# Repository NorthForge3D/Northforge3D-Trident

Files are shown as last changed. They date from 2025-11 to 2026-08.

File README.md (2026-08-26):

Project Currently on Hold (Aug 25, 2026). To come back better - with something completely different. Github update soon, all new. Youtube videos to come. New site coming online. We haven't abandoned it, we're just going to do it better!

<p align="center">
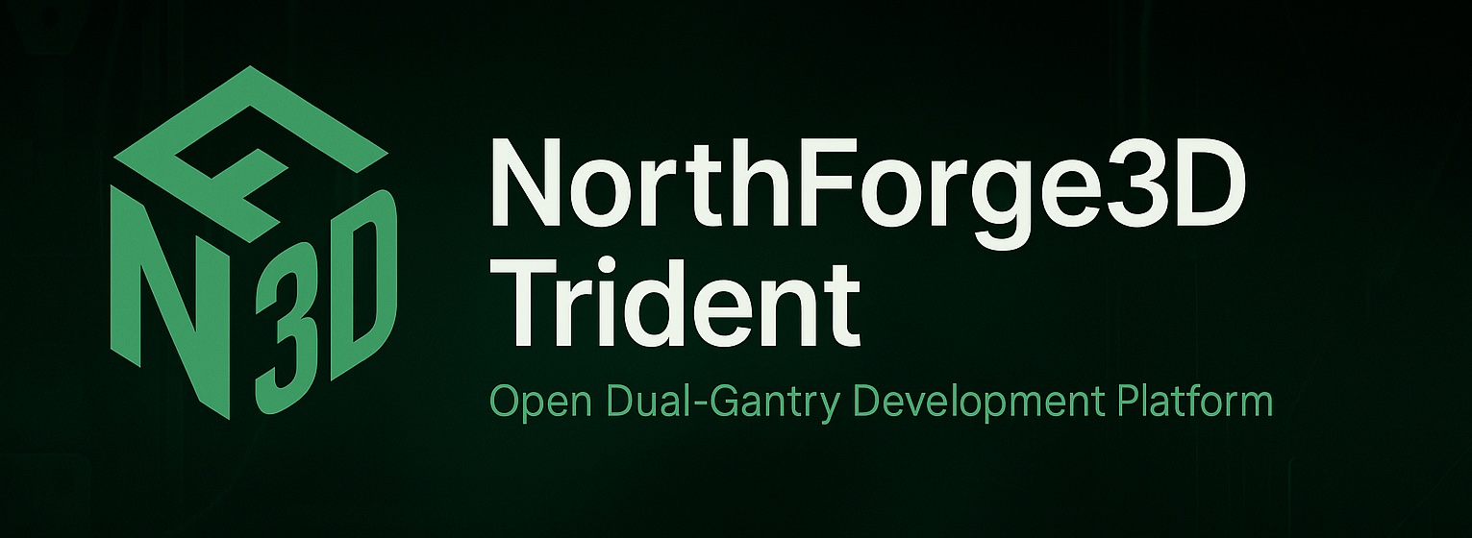
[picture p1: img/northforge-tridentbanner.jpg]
NorthForge3D Trident Banner
  
</p>

# NorthForge3D Trident – Open Development Platform for the Deuce  
### A dual-gantry proof-of-concept for the upcoming **NorthForge3D Deuce** – a next-generation, high-precision IDEX 3D printer.

---

## ⚠️ Experimental Project — Do Not Build Yet

This repository is under **active development** and contains **early, unstable, and rapidly changing work**.

The NorthForge3D Trident is our **motion lab**: a Trident-footprint, dual-gantry platform we’re using to prove out the mechanics, motion control, and behavior that will define the Deuce.

It is **not**:

- A finished printer  
- A drop-in Voron derivative  
- A recommended build at this stage  

- It will be a modded Voron Trident, with dual gantry printing.
- A really cool build if you want to watch and build one yourself
  
If you’d like to follow the progress—and get updates as this build and eventually our printer the Deuce evolve—you can start here:

👉 **Follow the Trident Build and the Deuce as They Evolve**  
https://northforge3d.com/forge-with-us/

👉 **Main Site**  
https://northforge3d.com

A full video series will be published once the Modded Trident design stabilizes.

---

## 🔥 What This Project Is

This repository documents the **engineering, testing, and evolution** of the NorthForge3D **Trident-based dual-gantry test platform**.

Think of it as our:

- Dual-gantry motion testbed  
- Toolhead choreography sandbox  
- Collision-avoidance and synchronization playground  
- Early electronics and layout experiment  
- Mechanical R&D platform for the Deuce

Everything here is **iterating frequently**. Expect redesigns, experiments, and the occasional controlled chaos.

---

## 🎯 Goals of the Proof-of-Concept Printer

### 1. Validate Dual-Gantry Motion

We need a reliable platform to test:

- Independent toolheads  
- Parallel / mirror / duplication print modes  
- Coordinated multi-tool workflows  
- High-speed motion with tight synchronization  
- Collision detection / avoidance strategies  

### 2. Redesign Major Subsystems

While this machine starts from a Trident footprint, it will diverge significantly:

- Fully redesigned **bottom section**  
  - No Voron skirt  
  - **Inverted electronics** visible inside the chamber  
  - Clean, service-friendly layout
- Raspberry Pi on a custom plate with **side-facing ports**  
- Redesigned **dual (eventual quad) gantry**  
- Lightweight toolheads  
- Filament cutter v2  
- New cable routing approaches  
- Modified or fully custom gantry components  
- Custom motors, pulley arrangements, and belt routing as needed  

### 3. Prototype a Production-Forward Layout

This proof-of-concept exists to test:

- Thermal behavior inside the frame  
- Cable access and serviceability  
- Component placement and reach  
- Mechanical accessibility and maintenance paths  
- The aesthetic and functional “feel” of a future NorthForge3D printer  

All of that informs the production-grade **Deuce**.

---

## 🧱 Hardware Decisions (So Far)

Current planned / in-use hardware includes:

- **0.9° NEMA 17 motors** – ~0.54 Nm, 42×48 mm  
- **0.9° pancake steppers** for toolheads  
- **T8×2 (single-start) lead screws** for ultra-fine Z resolution  
- **Klipper-based electronics**  
- Raspberry Pi with external-facing I/O  
- Additional hardware will be added as testing continues

Hardware choices may change as we prove things out.

---

## 📌 Status: Early Development

This repository is currently being **cleaned**, **reorganized**, and aligned to the new design direction.

In the near term:

- Remaining Voron-specific stl's will be removed - we'll re-export them with mods when we are done.  
- Bottom section redesign mod 
- Early dual-gantry motion tests will be shared  
- CAD development will continue in Fusion 360  
- Development logs will grow as milestones are reached, as we work  

Expect the design and structure here to change often as the NF3D Modded Trident comes together.

---

## 📅 Development Logs

We’re documenting progress in plain language as the project evolves. Logs will capture:

- CAD progress  
- Mechanical R&D  
- Firmware experiments  
- Toolhead ideas and tests  
- Renders / photos as the machine takes shape  
- Iterative design changes  
- Lessons learned and upcoming plans  

Long term, these logs will pair with a video series and deeper written documentation.

---

## 🧪 This Is Not the Deuce

The final **NorthForge3D Deuce** will be:

- Larger and fully enclosed  
- Built on a larger extrusion frame  
- Outfitted with production-grade electronics  
- Running refined dual-gantry mechanisms  
- Built with collision-resistant logic and robust safety considerations  
- Equipped with custom motors, pulleys, and motion components  
- Designed with full internal lighting and service access paths  

The Trident mod exists to **perfect the motion, firmware, and mechanical fundamentals** before we commit them to the Deuce. 

We've decided to use this printer to show you - how to build a printer that will outdo any printer you can buy off the shelf. You build it, you understand it, you can break it and fix it... it's what we do and you should to. 

A printer you build is your own. A Voron you build is better, faster, and more precise than your Bambu, any day of the week (sorry Bambu fan boys/girls)

---

## 🔗 Follow the Project

👉 **Website**  
https://northforge3d.com

👉 **Subscribe for Development Updates**  
https://northforge3d.com/forge-with-us/

👉 **Deuce Engineering Blog**  
https://northforge3d.com/forge-updates/deuce-updates/

👉 **Facebook** (short updates & announcements)  
https://www.facebook.com/NorthForge3D/

👉 **YouTube** (full build series coming)  
https://www.youtube.com/@northforge3d

👉 **Instagram** (visual progress, behind the scenes)  
https://www.instagram.com/northforge3d/

---

## 📜 License

This project is currently released under the **GNU GPLv3** license.

As the proof-of-concept solidifies, we will clearly identify:

- Which components originate from Voron Trident  
- Which mods are original NorthForge3D designs  

The license will remain **GPLv3**.

---

## 🤝 Contributions

This is an active engineering development project.  
Contributions and discussion are welcome — just be aware that:

- The design moves quickly  
- Files may be reorganized  
- Some ideas will be replaced as better solutions emerge  

If you’d like to collaborate, please open an **issue** or a **pull request**.

---

### 📘 Additional Project Files

👉 **[CHANGELOG.md](./CHANGELOG.md)** — Full development history  
👉 **[DESIGN-NOTES.md](./DESIGN-NOTES.md)** — Thoughts / Decisions / The Why

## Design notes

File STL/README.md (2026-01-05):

# STL Files — NF3D Trident

This directory contains STL files for the **NF3D Trident** build.

All STL files housed here have been **validated through real-world use** and have been printed and confirmed on an operating printer. These files may be downloaded, printed, and used to build your own NF3D Trident.

Most STL files in this directory **diverge from the stock Voron Trident design**. They are **not interchangeable** with standard Voron Trident parts unless explicitly stated. Substituting these parts into a stock Trident build, or vice versa, may result in fitment or functional issues.

Only tested, confirmed parts are included here. Experimental or in-progress designs are intentionally excluded.

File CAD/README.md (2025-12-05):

# NorthForge3D – CAD Directory

This directory contains all CAD work related to the NorthForge3D Trident-based
proof-of-concept printer. The goal of this phase is to validate key design 
modifications in CAD before physical construction begins.

The work here includes:
- A redesigned electronics bay
- Structural frame stiffeners
- Updated panel system
- Modified gantry and motion components
- A complete reassembled model for fitment and validation

The CAD in this directory represents the *working* design files.  
Reference files for the original Trident configuration are included for comparison.

For more information about the NorthForge3D project and the vision behind our printers,
visit **https://northforge3d.com**

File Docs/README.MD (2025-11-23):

# Documentation — NorthForge3D Trident

This directory contains documentation, notes, images, and design references for the Trident dual-gantry proof-of-concept.

---

### Expected Contents

- Mechanical notes  
- Motion-system diagrams  
- Testing procedures  
- Renders and photos  
- Early development reports  
- Future Deuce reference material  

More documentation will be added as development progresses.

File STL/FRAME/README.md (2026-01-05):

# Frame — NF3D Trident

The parts in this directory are **optional frame stiffeners** designed specifically for the **first dual-gantry NF3D Trident**.

These parts are included for two reasons:

1. **Frame Stiffening**  
   When installed, these parts increase overall frame rigidity.  
   Use of these parts requires **additional M5 fasteners and T-nuts** beyond the standard Trident bill of materials.

2. **Frame Squaring Aid (Use With Caution)**  
   If printed on a **well-tuned printer** and **confirmed to be exactly square using a machinist square**, these parts can assist in building and squaring the entire frame during assembly.

   ⚠️ **Warning:**  
   If printer accuracy and part squareness are **not verified with a machinist square**, these parts may **lock errors into the frame** rather than correct them. In this case, they can work *against* you instead of helping.

These parts diverge from the stock Voron Trident design and are intended for use only with the NF3D Trident geometry and documentation.

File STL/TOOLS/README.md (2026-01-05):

# Tools — NF3D Trident

This directory contains **tools and jigs** used to build the **NF3D Trident**.

Files in this directory are **not printer parts**. They are intended to assist with fabrication, alignment, and modification tasks during the build process (e.g. drilling jigs, alignment guides, and setup tools).

Some tools in this directory may be **generally useful** for other builds or projects. Others are **specific to the NF3D Trident** and are designed to be used in conjunction with this printer’s geometry and documentation.

All tools housed here have been **used and validated** during the NF3D Trident build process. Improper use may result in permanent damage to parts or materials—review the associated documentation before use.

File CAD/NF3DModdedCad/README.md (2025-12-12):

# NF3D Mods to Trident Cad

This directory contains the complete reassembled CAD model of the 
NorthForge3D Trident proof-of-concept printer.

This assembly links together:
- Frame subsystem
- Electronics bay
- Panels
- Gantry and motion system

Purpose:
- Validate clearances
- Confirm alignment between subsystems
- Check interference and fitment
- Visualize the printer as a whole prior to prototype construction

This assembly is the single source of truth for reviewing the current state 
of the printer design.

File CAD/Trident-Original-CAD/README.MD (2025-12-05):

## Trident Original CAD – Reference Only

This directory contains the pristine, unmodified CAD files of the original 
Voron Trident design.

These files are used strictly for:
- Measurement reference
- Comparison against NorthForge3D modifications
- Alignment checks
- Ensuring compatibility during early development phases

Do not modify these files.  
They serve as the fixed reference baseline for the entire project.

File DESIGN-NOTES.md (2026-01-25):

# DESIGN NOTES

Design Notes exist to capture **why** decisions were made, not just **what** was done.

While `CHANGELOG.md` records concrete actions and visible progress, this file documents the reasoning, tradeoffs, constraints, and forward-looking thoughts that led to those actions. Together, they form a linked record:

- **CHANGELOG.md** → what was built, changed, or tested  
- **DESIGN-NOTES.md** → why those choices were made, and what alternatives were considered

Entries here may include incomplete ideas, exploratory thinking, or decisions that evolve over time. That is intentional. This file is a living design journal meant to provide context for future work, explain past decisions to collaborators or builders, and make the project’s direction understandable long after individual commits are forgotten.

## 2025-01-24 — Dual Gantry Trident: v1 Build Volume Decision (Reduced X)

For the first dual-gantry Trident build, I am intentionally **accepting a reduced X build volume** rather than modifying the bed position, frame depth, or gantry geometry.

With two toolheads sharing the X axis, a stock-geometry Trident naturally loses usable X travel equivalent to roughly one toolhead width. In this configuration, the expected expectation for v1 is approximately:

- **~230 mm X**
- **~300 mm Y**
- **~200 mm Z**

This is a deliberate choice.

While there are multiple ways to recover X travel (moving the bed rearward, redesigning bed mounts, extending the frame depth, longer rails, or re-centering gantries), each introduces additional variables that complicate early tuning and validation.

For the v1 dual-gantry platform, the priority is:

- Validate dual-gantry mechanics and synchronization
- Tune motion, resonance, and input shaping without custom geometry side effects
- Observe real-world behavior of two moving toolheads under load
- Identify print artifacts with confidence they are *motion-system related*, not geometry-induced
- Establish a known-good baseline before expanding the envelope

Introducing custom bed mounts or frame extensions at this stage risks creating failure modes that are difficult to isolate (e.g. tall-print artifacts, thermal relaxation, shifted center of mass, or stiffness asymmetries).

A slightly reduced build volume is an acceptable trade-off in exchange for:
- cleaner diagnostics
- faster iteration
- higher confidence in conclusions drawn from test prints

Once the dual-gantry system is mechanically and dynamically validated, a future revision can safely reclaim X travel through controlled, well-understood changes (longer rails, adjusted frame depth, or revised bed mounting).

This decision is intentional and scoped to **v1 validation**, not a permanent limitation.

## 2025-01-21 — Skirt Design Thoughts, Bed Mount Design

- Designing skirt pieces
  - Bottom Lexan electronics panel will need to bolt to the skirts and corner blocks
  - Corner blocks and skirts will include an inset to allow a flat bottom surface
  - Interface will include designed components that bolt into the skirts and corner blocks to retain the electronics panel

- Voron skirts are very open
  - For the inverted electronics bay, temperature control is required
  - Electronics bay is sealed from the chamber via the removable clear access panel
  - Control board can measure its own temperature; no separate thermistor required
  - Fans will control airflow
  - Skirt pieces will be mostly closed to allow software-based temperature control of the electronics bay

- Bed mount redesign
  - Bed needs to move rearward by approximately 40 mm
  - First revision must prioritize maximum stiffness
  - PAHT-CF will be used for initial bed mounts
    - Printable — confirmed
    - Shrinkage and annealing behavior must be characterized
    - First test batch is currently annealing
      - If dimensional changes are consistent across batches, compensation can be applied in CAD to ensure accurate final parts

## 2025-01-08 — Skirt / Corner Block Thoughts

- Printed the first corner block to confirm the STL
  - Part is confirmed
  - Slight design changes are needed to make it printable by less-capable printers

- Venting considerations:
  - Venting at the corners likely isn’t necessary
  - Venting through the skirts isn’t necessary on this printer
  - The printer has active fans to move air
  - Electronics bay is inverted and a good distance from the heated bed
  - Three fans are planned
  - Skirts are modular — others can add more fans if they choose

- Design changes:
  - Add chamfers and an inset panel to make corner blocks more printable
  - Add logos to the front corner blocks
    - NF3D logo on one side
    - Voron logo on the other
    - I’m changing a lot — it’s my printer now — but it started as a Trident and will remain the NF3D Trident

- Content / documentation:
  - Reviewed Part 2 in the **How to Build a 3D Printer Frame** playlist
  - Added a blog post to more clearly explain the cutting process
  - Linked the article at the top of the video description:  
    http://northforge3d.com/forge-updates/3d-printing-tutorials/how-to-cut-2020-aluminum-extrusion-for-a-3d-printer-frame/

- Hardware notes:
  - May need to bring one of the larger Vorons home from the shop
    - The Voron 0.2 isn’t large enough for some upcoming parts
    - The SOVOL experienced a clog
      - Reinstalled the MicroSwiss hotend
      - Ordered additional 0.4 mm hardened nozzles (arriving Monday)
      - Ordered an additional MicroSwiss hotend with 0.6 mm and 0.4 mm hardened nozzles
      - Original MicroSwiss hotend is likely approaching 600–800 hours

- Summary entry for this work is recorded in  
  [CHANGELOG.md — 2026-01-08](CHANGELOG.md#2026-01-08--confirming--unconfirming-parts--cut-video-posted)

## 2025-01-03 - Slow progress, ideas coming together
*(Related entry: [CHANGELOG.md — 2025-01-03](CHANGELOG.md#2025-01-03))*

- Spent the past couple of evenings working on skirts.
  - Finalized the electronics bay concept: a single removable panel with **three DIN rails**.
    - DIN rails are bolted to the panel via an **ABS interface**, holding the rails **15mm off the panel** to allow wire routing underneath.
    - Printed wiring channels between DIN rails, evenly spaced at **three locations** (front, middle, back).
      - Channels are printed in ABS and include pass-through ports for clean wire entry and exit.

- Corner skirts are intended to **add structural rigidity** to the frame — stiffer is better for this printer.
  - Design is still in progress for all skirt components and will be uploaded once complete.

- Set up the saw with the correct **aluminum-specific blade** and added a clamping system for accurate, repeatable cuts.
  - This portion of the build could be completed at the shop, but I cannot record anything there.
    - Documenting processes like *cutting extrusions*, *tapping extrusions*, and *drilling blind corners* will still be valuable to the community,
      even if kit builders won’t need to perform these steps themselves.

- Started printing gantry parts (A/B drives, etc.).
  - **Estimated timelines:**
    - CAD completion for skirts and electronics bay: **~1 week**
    - First frame build / test frame for gantry parts: **~1 week**
    - After that, we can build, test, and redesign specific **dual-gantry drive systems** on a physical frame.

## 2025-12-28 – Design Decisions, Skirts, Electronics

- After reviewing the current CAD more closely yesterday, I decided to **build the frame early**
  for the test gantries and iterate the design around a physical reference.
  - Ordered a new aluminum-specific mitre saw blade (old one was worn out; not available locally)
  - Ordered an additional M6 tap for European-spec 2020 extrusions

- Worked on CAD for skirts and the electronics bay
  - Most skirts need modification so the **bottom panel seats into them** rather than bolting up to them
  - Skirts must support **DIN rails** (three for this build) to keep wiring clean and visually organized
  - Electronics cooling plan:
    - Two intake fans (left and right) pulling in cooler room-temperature air
    - One exhaust fan at the rear expelling warmer air
  - Required skirt redesigns:
    - One side skirt for **Pi pass-through**
    - Left rear skirt for the **clip-in AC inlet / switch module** already on hand
    - Center front skirt redesigned to include a **screen interface module**
      - Screen will be optional and externally mounted
      - Simple mechanical interface so the printed screen enclosure clips into place
      - Possibly secured from the inside with fasteners

- Started printing parts for **test gantry one and two**
- Also began printing parts for the actual Trident build
  - A/B brackets
  - Idler pulley brackets
  - Having a real frame to work against will greatly improve visualization and iteration speed

- Frame build documentation plan:
  - Capture and record useful processes for other builders:
    - Cutting aluminum extrusion
    - Drilling for blind corners
    - Tapping techniques
    - General frame prep and accuracy tips (Squaring,etc )
- Related build progress logged in  
  → [CHANGELOG.md · 2025-12-28 – Skirts and Electronics](CHANGELOG.md#2025-12-28--skirts-and-electronics)

## 2025-12-27 - Gantry Thoughts, Bed Move

> Related work logged in **[CHANGELOG.md — 2025-12-27](CHANGELOG.md#2025-12-27---working-on-gantry-parts-electronics)**

- While working on flipping the gantry rails for a side-to-side dual gantry layout,
  two major constraints became immediately apparent:

  - **Bed placement**
    - The bed is currently too far forward on the Trident frame
    - For a dual gantry setup, the bed will need to move inward (more centralized)
    - This will require redesigned bed mounts specific to this build

  - **Rear Z rail / support structure**
    - The current rear Z MGN rail and support design will not work as-is
      for a side-to-side gantry configuration
    - Several possible approaches to address this:
      - Flip bed motors side-to-side and add an additional frame crosspiece
        to support the single now side mounted motor
      - Redesign gantry mounts so the gantries ride on MGN9 rails mounted
        on top of the 2020 extrusion instead of hanging below
      - Do not flip the gantry at all:
        - Keep the bed centralized
        - Allow printheads to approach from front and back
        - Likely the simplest solution, but **no commitment yet**

- Began printing parts for a physical test gantry
  - Original Trident A/B motor, pulley, and idler components
  - ZRunchoes Trident-sized dual gantry parts
    - These parts were designed for a different class of printer
    - As far as I know, they have not been implemented on a Trident
      despite being made parametric/resizable

- Purpose of the test gantry
  - Allows direct visualization of clearances and interference
  - Enables testing belt routing, pulley placement, and gantry spacing
  - Confirms feasibility before motors or final CAD are locked in
  - Supports rapid iteration without risking the primary frame

- Initial assessment
  - There is still a strong possibility that the original Trident
    A/B motor and pulley mounts can be retained
  - Idlers will need to be relocated
  - Physical assembly will determine whether this remains viable

## 2025-12-21 – Design Thoughts – CAD and Control Systems
↔ See related implementation work in [CHANGELOG.md – 2025-12-21](CHANGELOG.md#2025-12-21--motion-rails-and-electronics-kit-cad)

- Created motion rails in CAD and made them fully parametric so rail length can be adjusted easily while preserving motion constraints.
- No need to commit CAD on days like this.
  - Built supporting components
  - Imported reference electronics
  - No meaningful structural changes were made to CAD that lives in the repo
  - These are preparatory pieces required to continue design work cleanly
- For some imported CAD components, the models will need to be simplified.
  - Example: the **Biqu Octopus CAD** is a full, component-level electronics model
  - I do not need resistor-, IC-, or component-level detail
  - I only need:
    - Dimensionally accurate representations
    - Correct mounting geometry
    - Visual references for DIN rail placement and clearances
  - I am not wiring electronics in CAD
- Could not find CAD for the exact planned power supplies.
  - Used manufacturer dimensions to import a **Mean Well PSU** with closely matching dimensions
  - Dimensional accuracy matters for DIN rail mounts and placement
  - The full electronic detail does not matter here

- Spent time evaluating the current state of **Klipper and its forks**.
  - Thinking through how this system will ultimately work:
    - Two print heads “dancing”
    - Two heads printing a single part
    - Guaranteed non-collision behavior
  - May use **Kalico** for the first printer.
    - I believe I can demonstrate the concept largely through configs and macros
    - I built it, I understand it, and I won’t break it
  - Before releasing this as a kit—or releasing **The Deuce** as a production unit—I may need to fork **Klipper or Kalico**.
    - Collision avoidance for a dual-gantry system must live in the motion control software itself
    - It cannot live in:
      - G-code
      - The slicer
      - Config-only logic
    - A kit that relies solely on configuration-based collision avoidance will eventually be broken by users modifying configs
    - That results in broken machines
  - **The Deuce** is intended to be:
    - Expandable
    - Serviceable
    - Reliable
  - If adding or modifying a component can break the machine due to a configuration mistake, that is unacceptable
  - This will need to be revisited as we move through:
    - Mirror mode
    - Independent dual-head printing
    - Dual-color modes
    - Dual-material modes
  - A decision will need to be made, and the safest long-term solution for a kit or production machine is to make collision avoidance part of the system that directly drives the motors

## 2025-12-19 – Gantry Design Thoughts

- Frame expansion is complete.
- Next step is to expand, flip, and install the gantry correctly in CAD.

- The Trident gantry is currently linked as one solid piece.
  - It will need to be broken apart so individual components can be positioned correctly.
  - Single parts must be moved into place to create a proper, functioning motion system.

- For portions of the gantry work, it may be easier to source working CAD rather than fight what currently exists.
  - Example: MGN rails and blocks.
    - These must behave correctly in CAD.
    - I need to be able to grab a carriage block and have it move accurately along the rail.
    - Eventually, I should be able to grab a printhead and move it in CAD.
    - Belts, pulleys, and idlers must respond correctly so the full motion system is represented accurately.

- There is no reason to redesign Trident gantry mounts.
  - The design already works and is proven.
  - The task is to disassemble the existing CAD assembly and reassemble it piece-by-piece on the expanded gantry rails.
  - This includes adding correct motion behavior to idler pulleys, timing pulleys, and bearings.

- All of this work is necessary to properly prove the gantry and motion system in CAD before moving forward.

(See **[CHANGELOG.md → 2025-12-19 – Expand Exterior Frame in CAD](CHANGELOG.md#2025-12-19--expand-exterior-frame-in-cad)**)

## 2025-12-18 – New CAD and Decisions

- The Trident is built very bed-forward, so the gantry will need to be rotated sideways.
- This orientation reduces X/Y volume loss.  
  If a second gantry were added in the same orientation, we would lose:
  - The depth of the gantry rail
  - The printhead offset
  - Additional space for belts and the X pulley system
- Rotating the gantry preserves more usable X/Y volume and simplifies future expansion.

- Decided to use switching power supplies for this build.
  - Ordered **two 500W, 0–60V Hongpoe PSUs**
  - These are not as trustworthy as Mean Well units, but with a 4.8 rating and 300+ reviews on AliExpress, they should be sufficient for testing and development
  - Voltages will be tested and verified before connecting to any control boards

- Using switching PSUs allows flexibility as the system evolves:
  - Start with a standard 24V Klipper configuration using dual PSUs
  - Transition to 48V on the X/Y/Z rails once the dual gantry is printing reliably
  - Voltage headroom exists to go higher (up to ~56V if ever needed)
    - Not currently required, but the option exists
    - Control boards and drivers are capable of handling 60V max

### Why This (NEW CAD) Matters

- Creating a dedicated frame / gantry / electronics CAD allows the project to move to a **true 300 × 300 × 250 build volume**, instead of being constrained by the original Trident 250 × 250 × 250 layout.
- Working at the correct size enables:
  - Proper electronics layout at full scale
  - Skirts designed to the final footprint
  - Accurate DIN rail placement and power distribution planning
- This file also allows the **dual-gantry system to be designed and validated as a movable, working assembly** in CAD, at the correct size, before any physical assembly begins.
- Resizing and reworking the original Trident CAD would be slow and inefficient:
  - The file contains 300+ parts
  - Rescaling the frame, flipping X rails, reworking the gantry, and adding a second gantry would take 1–2 days just to reach a usable state
- Starting fresh with a purpose-built CAD significantly reduces friction:
  - Frame resize, electronics flip, and DIN-based layout can be completed in 2–4 days
  - Motion systems can be developed and tested in isolation without fighting the full Trident assembly
- Working in a smaller, focused CAD eliminates constant hide/show management of dozens of unrelated components, allowing faster iteration and clearer decision-making.
- This approach trades sentimental continuity for **speed, correctness, and forward momentum**, which is critical at this stage of the project.

→ Related log entry: **[CHANGELOG – 2025-12-18](CHANGELOG.md#2025-12-18)**

## 2025-12-17 – CAD Design & Build Decisions

- For the electronics bay, it will be simpler and cleaner to work from a **separate CAD file**.
  - This file will include the **full frame** and all **relevant structural reference parts**.
  - It will be expanded to the **standard build volume of 300 × 300 × 250**.

- This approach allows:
  - A **single source of truth** for skirts, electronics bay, gantry, and panels.
  - All parts to be designed together so **everything fits correctly by default**.
  - Accurate, repeatable dimensions that can be provided directly to suppliers if we decide to offer this printer as a **build kit**
    (e.g. *cut to this length, drill here*).

- The gantry CAD will be designed **with motion constraints**, allowing motion to be tested in CAD before committing parts to a physical printer.

- I may build this printer **twice**, in parallel, specifically for video documentation.
  - I already have enough extrusion to support this, assuming I don’t make excessive bad cuts or drilling mistakes.

- Reasoning:
  - When it comes time to cover electronics in video, running **48V and 24V rails simultaneously** is likely too much for most builders.
  - It increases complexity and frustration, and adds significant cost.
  - That setup makes sense for my **test rig**, and I may still document it on the blog and in advanced videos.
  - However, for **how-to and build-guide videos**, a simpler, more approachable configuration is the better teaching choice.

- The **second build** will:
  - Omit the frame stiffeners.
  - Use a more conservative, builder-friendly electronics setup.

- Saner electronics options under consideration for the second build:
  1. **Mellow High-Speed Super 8 Pro (3 + 5 HV)**
  2. **Makerbase SKIPR all-in-one board**
  3. **400W 24V power supply**

- These components will need to be tested for **repeatability and long-term reliability** before being considered for inclusion in any future kits.

## 2025-12-14

- Watching back the YouTube video: brackets printed on the Sovol show visible shift artifacts. Parts are still square, but for example/validation pieces, slow the printer down or use the Vorons. ABS prints benefit from lower speeds for both strength and dimensional precision. Note for future part confirmations and videos.
- Watching video back: it may be useful to record two points of view at once. Record my face and talking while recording my hands working. Easy way to do this, without compromising "I am not a youtuber, I have no intention of spending money on recording equiptment". Use the MacBook to record me, use the iPhone and the $20 arm I bought to record me working. This will be useful in future videos when we're building a large frame, etc. As I can switch views. This adds ~3 minutes of video editing time.

## 2025-12-11

- Reversal of original CAD separation. All CAD now housed in the NF3D-Trident file. This will improve workflow.
- Turned 1 bracket into 12 around the top. Loosely (messy CAD) placed them until I add the T-nuts and the M5 bolts.
- With the shortened printer, this stiffener design will work. If I built it taller, may need to consider weight. How much does 48 M5 bolts and 48 T-nuts add?
- This is the design for this shortened dual gantry Trident. May reconsider the number of braces if we decide to release this printer in kit form. Added stiffness is still more important for this first printer.

## 2025-12-09 — Top Frame Stiffeners Created in CAD, Validated by Printing

- 10mm × 20mm × 60mm corner brackets designed, 2 bolts per rail into T-nuts
- Tried to keep the aesthetics of the printer correct
- Will use these brackets around the top frame, and also at each X/Y corner once non-interference is confirmed
- Shortened build volume further stiffens the frame and benefits dual-gantry 48V motion

**STEP BACK** — separating CAD into parts was a bad idea. All new and future CAD will live in a unified NF3D Dual Gantry CAD directory. Original Trident CAD retained for reference.

## 2025-12-05 — Working CAD Structure / Workflow Started

- Designing frame stiffeners first
- Electronics bay next — flipped with a see-through panel for easy access
- Pi-through skirts housed in Electronics Bay CAD
- Early decisions here affect many downstream designs

## 2025-12-03 — CAD Structure & Workflow Decisions

- Established long-term CAD workflow for NF3D Trident POC
- Created modular structure:
  - ElectronicsBay
  - Frame
  - Gantry
  - Panels
  - NF3DReassembled
  - Trident-Original-Cad

- Reasoning:
  - Avoids a single massive Fusion file
  - Faster subsystem iteration in VR
  - Preserves a clean reference baseline

- Conclusion:
  - CAD workflow is now stable
  - Supports NF3D philosophy: design openly, iterate quickly, build only what’s validated

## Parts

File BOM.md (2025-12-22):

# **NF3D Trident – Prototype BOM (Experimental Build – Pushed to the Limits)**
### **Updated: Dec 09, 2025**
### *Premium overbuilt prototype – for testing, tuning, dual-gantry development*

Will be updated when all components arrive. Still waiting on bed, bed heater, high-flow nozzles, still to select power system (Dual PSU vs PSU and Buck... decision to be made when CAD electronics bay is done. If two stable PSUs fit cleanly, that is the prefered route for this build)

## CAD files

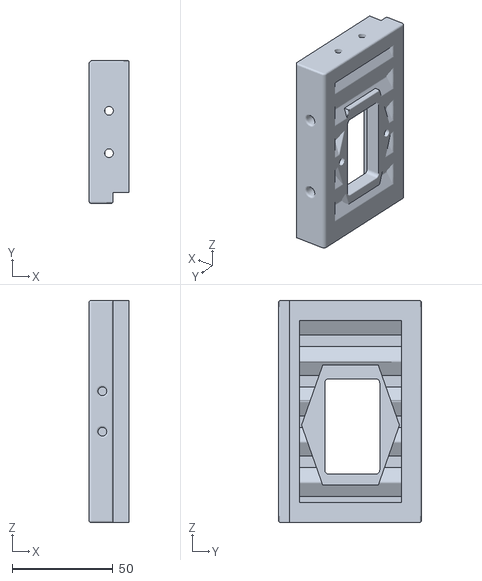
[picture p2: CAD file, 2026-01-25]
CAD/NF3DModdedCad/Skirt-Piece-AC-Plug-V1.stl
20.0 x 71.0 x 110.0

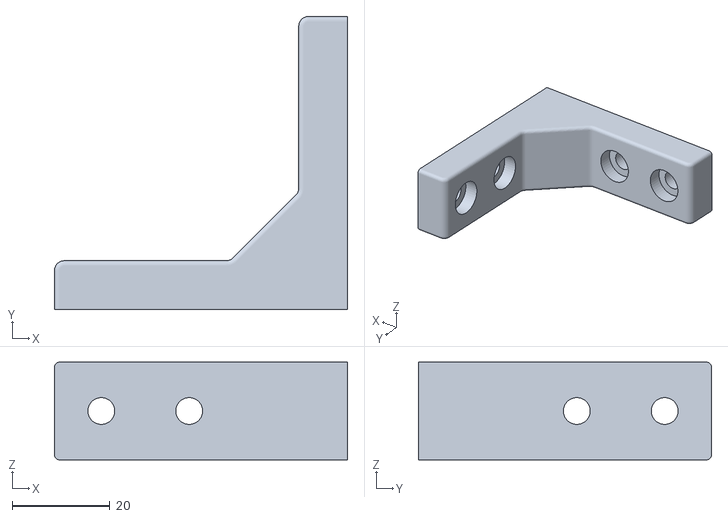
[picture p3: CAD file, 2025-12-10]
STL/FRAME/CornerBrackTop.stl
60.0 x 60.0 x 20.0

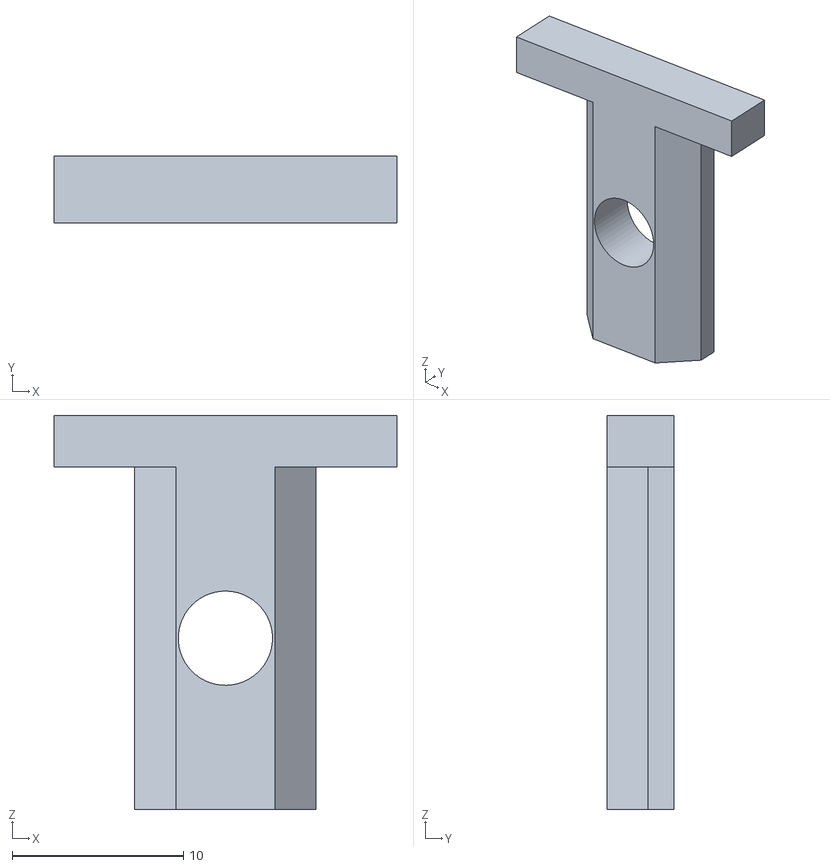
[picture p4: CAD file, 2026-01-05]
STL/TOOLS/BlindCorner-Drill-Jig-Single.stl
20.0 x 3.90 x 23.0

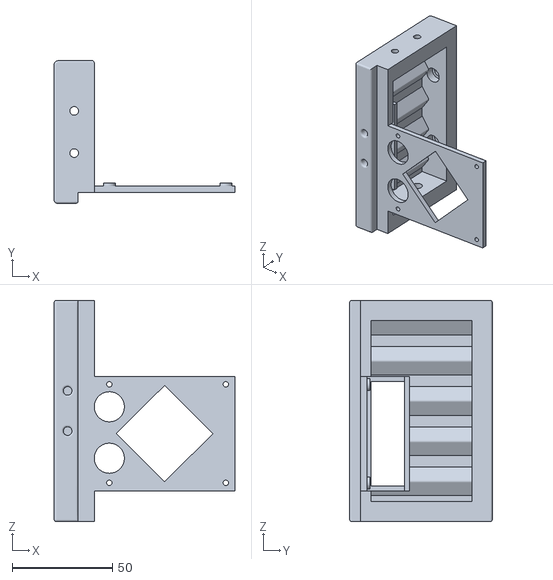
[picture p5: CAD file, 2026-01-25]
CAD/NF3DModdedCad/Skirt-RPi4PassThrough-V1.stl
90.0 x 71.0 x 110.0

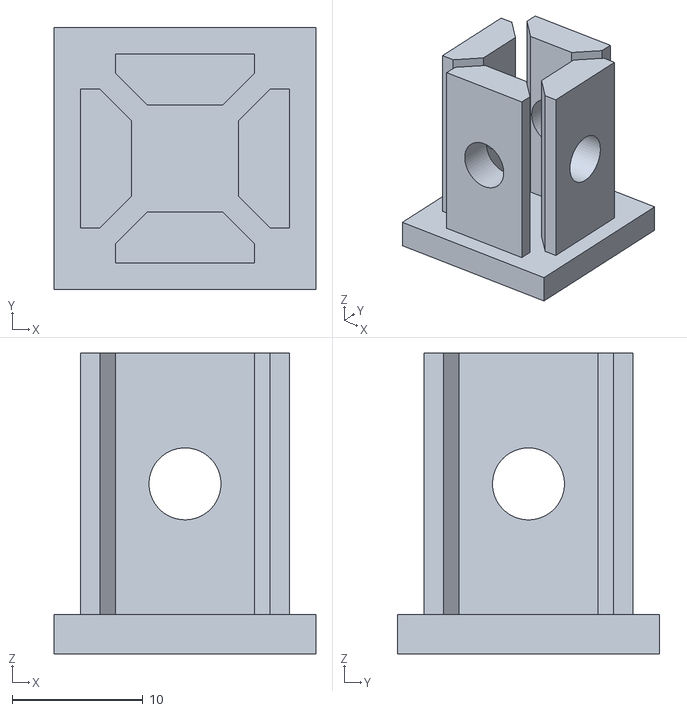
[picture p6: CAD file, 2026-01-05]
STL/TOOLS/Blind-Corner-Jig.stl
20.0 x 20.0 x 23.0

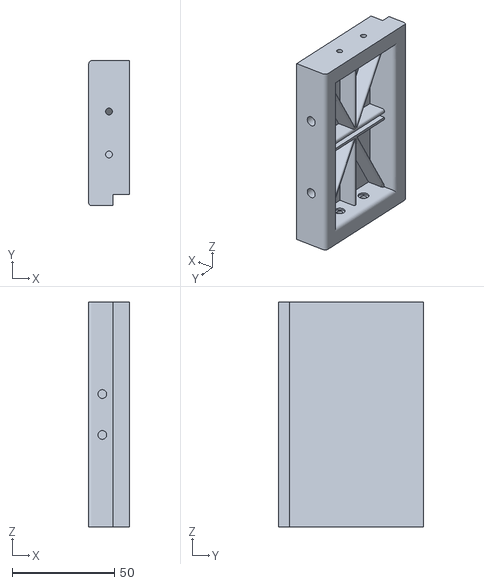
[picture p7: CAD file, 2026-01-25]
CAD/NF3DModdedCad/Skirt-Block-Canidate-Real1.stl
20.0 x 71.0 x 110.0

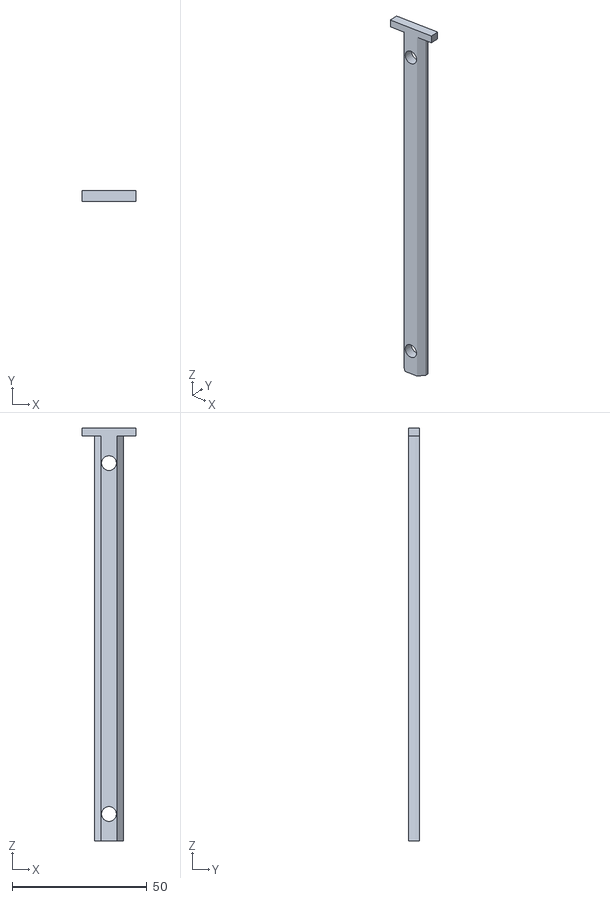
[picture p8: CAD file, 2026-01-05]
STL/TOOLS/Gantry-Drill-Jig.stl
20.0 x 3.90 x 153.0

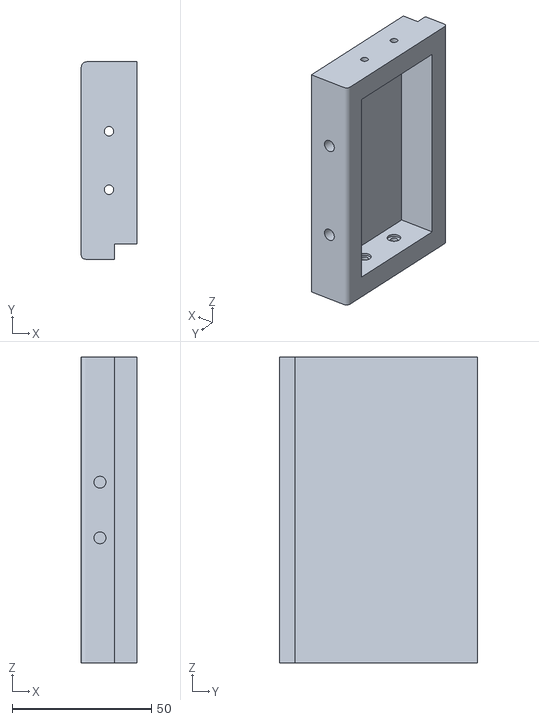
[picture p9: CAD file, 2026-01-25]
CAD/NF3DModdedCad/SkirtBlackTest.stl
20.0 x 71.0 x 110.0

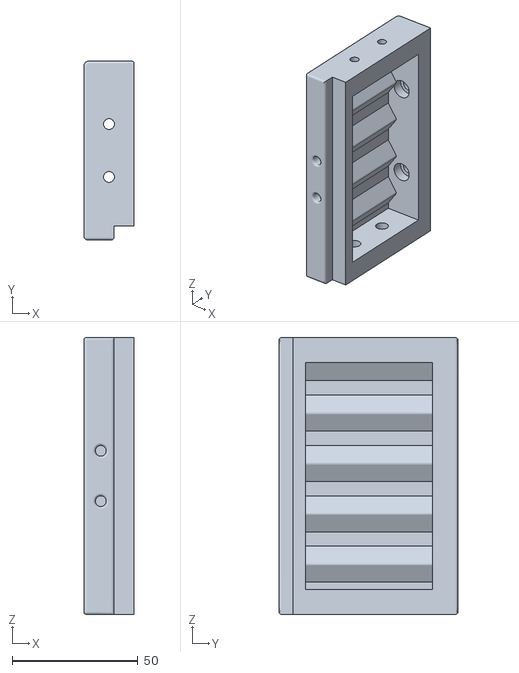
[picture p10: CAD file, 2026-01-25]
CAD/NF3DModdedCad/Blank-Skirt-V4.stl
20.0 x 71.0 x 110.0

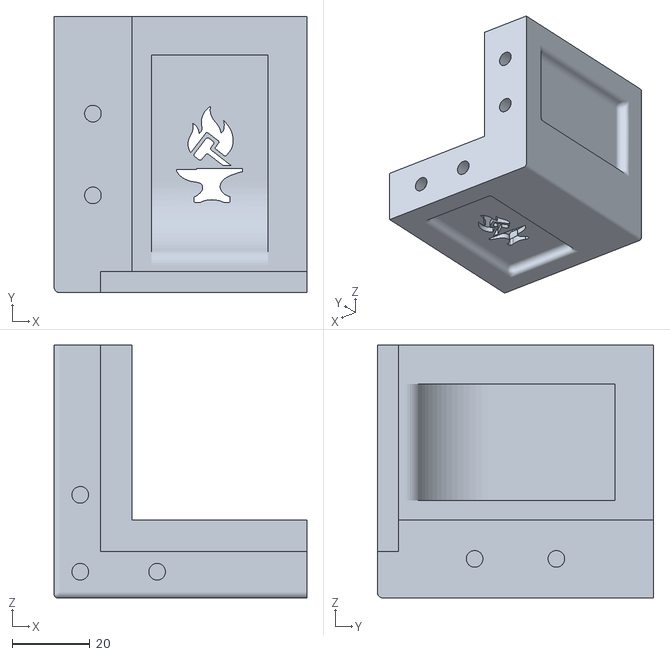
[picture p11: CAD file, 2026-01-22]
CAD/NF3DModdedCad/Corner-Skirt-NF3DIconLogo-needs-supports.stl
65.0 x 71.0 x 65.0

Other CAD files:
CAD/NF3DModdedCad/BlankSkirt-Candidate3.stl
CAD/NF3DModdedCad/SkirtBlock-Candidate1-LF-Normal.stl
CAD/NF3DModdedCad/BlankSkirt-V2-PrintTest.stl
CAD/NF3DModdedCad/CornerBracket-FrontLeft-VoronLogo.stl
CAD/NF3DModdedCad/Corner-Piece-Blank-Confirmed.stl
CAD/NF3DModdedCad/NF3D-Frame-Electronics-Gantry.f3d

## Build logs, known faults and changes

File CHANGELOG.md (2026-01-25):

# CHANGELOG

The changelog records **what changed and when** as the project progresses.

This file focuses on concrete actions: CAD work completed, parts created or modified, files added or removed, and decisions that materially affected the state of the project. Entries are chronological and factual by design.

When important design rationale, tradeoffs, or forward-looking thinking influenced a change, those details are captured in **DESIGN-NOTES.md**, and entries here link back to the corresponding design notes where appropriate.

Together:
- **CHANGELOG.md** documents *what was done*
- **DESIGN-NOTES.md** explains *why it was done*

Both are maintained intentionally to preserve context, trace decisions, and make the project understandable to future contributors, builders, or reviewers.

## 2025-01-24 — Skirts Being Confirmed

- Designed and began printing the modular skirt system
  - Three modular pieces between each corner block
  - Blank skirt piece — designed and printed
  - AC plug skirt piece — designed and printed
  - Raspberry Pi 4B pass-through piece — designed and currently printing
  - Still to design:
    - Fan skirt piece
    - Screen mount skirt piece
- Plan to bolt all skirt pieces to the frame to confirm STL files and print fitment

## 2025-01-21 — Skirts in CAD, PAHT-CF Testing

- Placed all corner blocks for skirts correctly in CAD
  - Front Left — Voron Logo Cutout Block  
    - Printed and verified
  - Front Right — NF3D Icon Logo Cutout Block  
    - Printed and verified  
    - Current version requires supports; will likely simplify geometry to make printing easier for others

- Designed outline of the first modular skirt system
  - Three skirt segments per side, ~110 mm each, between corner blocks
  - All skirt segments bolt together using heat inserts and M3 fasteners
  - Outer skirt segments bolt to corner blocks using heat inserts and M3 fasteners

- Printed first controlled test set to evaluate **Elegoo PAHT-CF** material properties  
  (see DESIGN-NOTES.md → *2025-01-21 – Skirt Design Thoughts, Bed Mount Design*)
  - Two Orca tolerance test blocks (known, repeatable reference geometry)
    - Used to evaluate 5 mm Allen key fit across multiple hole sizes
    - Post-anneal fit will be compared to pre-anneal results
  - Voron calibration cube (dimensionally measurable reference)
  - Top frame stiffener
    - Previously verified to print perfectly square on this printer
    - Confirmed square with PAHT-CF using machinist square, and also measured using digital calipers
    - Will be re-measured after annealing to confirm dimensional stability

- First annealing batch
  - Annealed at **200 °F (≈93 °C) for 4 hours**
  - Conservative temperature/time chosen for initial characterization
  - Goal is to determine:
    - onset of shrinkage
    - dimensional change behavior
    - consistency across parts and geometries

## 2025-01-18 — Logos Added to Corner Skirt Pieces

- Brief hiatus to repair a required printer for this project (lost ~1 week)
  - Burned out a control board (operator error)
    - Replaced with an MKS SKIPR
    - Poorly documented for this printer
      - Configurations built from scratch, which took additional time
  - Goal is to print the first modified bed mounts in PAHT-CF
  - Need to better understand annealing shrinkage/contraction so it can be accounted for in CAD
  - Voron 0.2 is operational again
    - Swapped extruder motor to 0.9° stepper
    - Retained Dragonfly BMO hotend and RepRap nozzle
    - Currently printing very well with ASA-GF

- Added Voron logo cutout to the left front corner skirt block
  - Includes a separate insert intended to be printed in translucent filament and backlit

- Added NF3D forge icon to the right front corner skirt block
  - Includes a separate insert intended to be printed in translucent filament and backlit

- Voron version currently printing to confirm fit and finish

## 2026-01-08 — Confirming / Unconfirming Parts · Cut Video Posted

- Printed the first corner block to confirm it isn’t too bulky
  - Confirmed dimensionally correct
  - Heat-set inserts will work
  - Interface with skirts will work
  - Minor design changes needed
    - Larger vent holes intended for airflow (the skirts will not be vented here) resulted in a 30–40 mm bridge regardless of print orientation
      - Normally this is considered carefully during design; this was overlooked
      - The part printed successfully anyway, but printers not tuned for bridging would likely struggle
        - Venting here is unnecessary — replace with chamfers and an inset panel
        - This also creates a good location for logos or design elements

- Posted Part 2 of the YouTube series **How to Build a 3D Printer Frame**:  
  https://www.youtube.com/watch?v=fNyRXwP5xbI

- Detailed design thoughts and decisions for today are documented in  
  [DESIGN-NOTES.md — 2025-01-08](DESIGN-NOTES.md#2025-01-08--skirt--corner-block-thoughts)

## 2026-01-07 — Skirt Work

- Continued work on the skirt system
  - Began designing a **three-piece, between-the-corners skirt system**
    - Once a single block is finalized, skirts can be printed in that form
    - Three skirt pieces between each corner block
    - Planned variants:
      - Pi passthrough section
      - AC inlet / switch section
      - Screen mount section
    - Current design targets **300 mm build size only**
    - All pieces:
      - Friction-fit using designed tabs
      - Bolt to the bottom frame
      - Bolt into the corner blocks
      - Considering a simple one- or two-bolt skirt-to-skirt connection using heat-set inserts to reduce flex and prevent the skirt from feeling flimsy when lifting the printer

  - Corner block (blank version) is printing to validate:
    - Overall size and proportions
    - Bulk vs. stiffness balance
    - Intended to add bottom-frame stiffness without excessive bulk
    - Design can still be easily adjusted before completing the remaining skirt components

## 2026-01-06 — Updates / Videos

- Continued work on printer skirt design
  - Switched to a modular skirt system
  - Corner pieces completed; designed to add stiffness at the lower frame
  - Side skirts designed as interchangeable modules
    - Three repeatable sections between each corner
    - Center section can be swapped (e.g. no screen, alternate panel)
    - Front pass-through ports can be relocated by swapping modules
    - All skirt modules interface identically for flexible configuration

- Cut the printer frame extrusions
  - Tapping, drilling, and final prep still pending

- Started a new YouTube series: *How to Build Your Own 3D Printer Frame*
  - Intro video published explaining how to derive frame dimensions from the Voron BOM
  - Playlist created to document the full cut / drill / tap / assembly process
  - Video: https://www.youtube.com/watch?v=7mM1ULKVuBA

## 2026-01-04 — Frame cut, STL folder added

### Frame Preparation
- Cut all aluminum frame extrusions to final size.
  - Frame geometry remains identical to the original Voron Trident.
  - Overall height reduced by **50 mm** for this build.
  - Used **vorondesign.com** to derive the full cut list from Misumi part numbers.
  - All 2020 extrusions cut to length.

### Jigs & Tooling
- Designed custom CAD drilling jigs for:
  - Blind corner holes
  - Gantry mounting holes at precise offsets from the top of the frame
- Printed all required drilling jigs.

### Repository Structure
- Added `STL/` folder to the repository.
  - This directory will house all validated and tested STL files.
  - Current structure:
    - `STL/Frame/` — frame stiffener parts
    - `STL/Tools/` — drilling and alignment jigs
  - Added README files to `STL/` and all subdirectories.

### Documentation & Media
- No updates to `DESIGN-NOTES.md` tonight.
  - Frame design rationale was fully captured in the previous entry.
- Recorded a video documenting the 2020 extrusion cutting process.
  - Video will be published to the YouTube channel tomorrow or the following day.

## 2025-01-03
*(Related entry: [DESIGN-NOTES.md — 2025-01-03](DESIGN-NOTES.md#2025-01-03---slow-progress-ideas-coming-together))*

- Continued work on redesigned skirts.
  - Corner blocks will be similar in concept to the **top frame stiffeners**.
    - Extend **60mm outward** from each corner.
    - Include **two M5 bolts into T-nuts** per rail (4 total) to clamp the frame tightly.
    - Each corner includes an interface to accept the next rail section.

  - Skirt pieces will bolt **to each other** and **to the frame** for added rigidity.

  - Bottom of skirts includes a **5mm inset**.
    - Electronics panel will sit inside this inset.
    - On the first printer, this panel will be made from **1/4\" Lexan**.

  - Electronics panel mounting strategy:
    - Panel is held upward into the skirts using brackets.
    - Two brackets per side, plus additional attachment near the corner feet.

  - Corner feet design:
    - ABS bracket bolted into the corner to support the electronics panel.
    - TPU foot approximately **10mm thick** for vibration isolation and grip.

- See corresponding **design rationale and planning notes** in the linked Design Notes entry above.

## 2025-12-28 – Skirts and Electronics

- See related design thoughts in  
  → [DESIGN-NOTES.md · 2025-12-28 – Design Decisions, Skirts, Electronics](DESIGN-NOTES.md#2025-12-28--design-decisions-skirts-electronics)

- Started working on new skirts for inverted electronics and pass-through Pi
  - Imported Trident skirts and separated out the pieces I will and won’t use
  - Corner pieces are usable as-is
  - Identified required changes:
    - New front skirt to support an **external-mounted screen** (optional, not required for base build)
    - Right-side skirt redesigned for **USB / Pi pass-through**
    - Rear skirt redesigned for an **all-in-one module** (AC inlet + rocker switch)

- Imported most electronics components into CAD:
  - Mean Well LRS-350-48
  - Mean Well RS-25-5
  - 48V → 24V buck converter
  - SSR and related hardware

- Began printing frame stiffeners and gantry parts for visualization and fit testing

## 2025-12-27 - Working on Gantry Parts, Electronics

- See related design thoughts in **[DESIGN-NOTES.md — 2025-12-27](DESIGN-NOTES.md#2025-12-27---gantry-thoughts-bed-move)**

- Started working on flipping the gantry for side-to-side dual gantry
  - Drilled new holes and moved the gantry rails to the front and back
  - Identified multiple issues that will need to be addressed for this approach to work:
    - Bed will need to be moved further back (more centralized in the frame)
    - Rear Z MGN rail / support will need to be moved inward or
      an additional rear frame crosspiece added below the rear gantry rail
    - In practice, **both changes will likely be required** — see Design Notes

- Started printing test pieces
  - Standard Trident A/B motor mounts and idler mounts
  - ZRunchoes dual-gantry-related parts (Trident-sized variants)
  - Building a physical test gantry to visualize layouts and interference
  - Goal is to validate clearances, belt routing, and mounting before final CAD
  - Enables rapid iteration: parts can be installed, evaluated, or discarded quickly

- Began simplifying CAD models for electronics
  - Example: Octopus Pro now represented as a dimensionally correct simplified model
  - Color and envelope preserved for electronics bay layout
  - Detailed board CAD removed where not needed

- No CAD commits made yet
  - Will commit once electronics bay and skirts are finalized
  - Gantry and Z-axis modifications will be committed separately once resolved

## 2025-12-21 – Motion Rails and Electronics Kit (CAD)
↔ See related design thoughts in [DESIGN-NOTES.md – 2025-12-21](DESIGN-NOTES.md#2025-12-21---design-thoughts---cad-and-control-systems)

- Began creating the foundations of the motion system to allow the gantry to be expanded to the newly defined, properly sized frame.
  - Created **MGN9 rails and MGN9H blocks** in CAD.
    - Fully parametric
    - Assembled with proper motion constraints (blocks slide on rails)
  - Created **MGN12 rails and MGN12H blocks** in CAD.
    - Fully parametric
    - Assembled with proper motion constraints
- Began locating and importing representative electronics components for the electronics bar:
  - **BTT Octopus Pro v1.1** imported and positioned in CAD
  - **Raspberry Pi 4** imported and positioned in CAD
  - **Two representative power supplies** imported and positioned in CAD
- CAD was **not committed** today.
  - No meaningful architectural changes were made
  - This work focused on creating prerequisite parts required for the next design step
- Design rationale and system-level thinking captured in **DESIGN-NOTES.md**

## 2025-12-19 – Expand Exterior Frame in CAD

- Working in the new CAD, expanded the exterior frame to proper dimensions for a 300 × 300 × 250 build volume
- Exterior frame is now correctly sized at **460 × 460 × 500 (H)**
- All frame joints are now rigid, making this a true structural frame rather than loose extrusions
- Electronics planning update:
  - Ordered DIN rails, terminal distribution blocks, and DIN-mounted AC and DC fuse holders
  - This will allow for a much cleaner, more serviceable, and showpiece-level electronics bay

**Next steps:**
- Expand remaining aluminum frame components
- Expand and place the gantry
- See **[DESIGN-NOTES.md → 2025-12-19 – Gantry Design Thoughts](DESIGN-NOTES.md#2025-12-19--gantry-design-thoughts)**

## 2025-12-18
---
- Moved the frame, gantry, and electronics into a new CAD file:  
  **NF3D-Frame-Electronics-Gantry.f3D**
- Removed all parts not required for this portion of the CAD
  - Work will now focus only on the larger structural and system-level modifications
  - Electronics were intentionally kept and will be flipped, repositioned, and reorganized
  - New skirts will be designed to support:
    - An inset bottom panel
    - Support for 2–3 DIN rails
    - A Pi pass-through design to allow USB / HDMI access from outside the printer
- Updated **DESIGN-NOTES.md** with rationale and design decisions  
  → See: **[2025-12-18 – New CAD and Decisions](DESIGN-NOTES.md#2025-12-18---new-cad-and-decisions)**

## 2025-12-17
---

- Redesigned and modified the **bottom front brackets**.  
  - They now function as **frame stiffeners** and **bottom clear panel holders**.  
  - Interface cleanly with **VORON motor mounts**.  
  - Will print and physically validate this weekend.

- Added **frame stiffeners along the rear X/Y** by duplicating the top bracket design.

- Decided **no additional stiffening is required on the bottom**.  
  - Skirts, motor mounts, and existing structure already contribute sufficient rigidity.

- Ready to move on to **Electronics Bay / Skirts**, followed by a **working CAD gantry**.

- Downloaded CAD for the **electronics boards selected for the first build**.

- Added a detailed entry to **DESIGN-NOTES.md** covering current CAD, build, and kit-planning decisions:  
  → [2025-12-17 – CAD Design & Build Decisions](./DESIGN-NOTES.md#2025-12-17---cad-design--build-decisions)

## 2025-12-16
---
- Designed initial **bottom frame stiffeners** intended to both increase frame rigidity and act as a **drop-in deck panel support**
- Defined deck panel requirements:
  - Must be **easily removable** for electronics access
  - Should **drop in** and allow **lift / flip-up access**
  - Electronics will likely be **inverted-facing** for aesthetics, but must remain serviceable
  - This orientation is required for the first build and may become permanent
- **Concept not committed**:
  - Current design needs refinement
  - Must provide real frame stiffening — **accomplished**
  - Must function as a simple panel mounting system — **accomplished, but needs refinement**
  - Must **not interfere with existing Voron Z-motor mounting** (no redesign justified)
- Deck panel design must remain **simple to manufacture** (easy to cut; no unnecessary complexity)

## 2025-12-14

- Watching back the YouTube video: brackets printed on the Sovol show visible shift artifacts. Parts are still square, but for example/validation pieces, slow the printer down or use the Vorons. ABS prints benefit from lower speeds for both strength and dimensional precision. Note for future part confirmations and videos.
- Watching video back: it may be useful to record two points of view at once. Record my face and talking while recording my hands working. Easy way to do this, without compromising "I am not a youtuber, I have no intention of spending money on recording equiptment" .. Use the macbook to reocrd me, use the iphone and the $20 arm I bought to record me working. This will be useful in future videos when we're building a large frame, etc. As I can switch views. This adds 3 minutes of video editing time...

## 2025-12-11

- Reversal of original CAD separation. All CAD now housed in the NF3D-Trident file. This will improved work flow.
- Turned 1 bracket into 12 around the top. Loosely (messy cad) placed them until I add the t-nuts, and the m5 bolts.
- With the shortened printer, this stiffener design will work. If I built it taller, may need to consider weight. How much does 48 M5 bolts and 48 t-nuts add in weight?
- This is the design for this shortened dual grantry trident, may reconsider the number of braces if we decide to release this printer in kit form. If I stiffen significantly (I have) but add a 0.5 - 0.8kg of weight at the top, I may reduce movement at the joints but increase the wobble in the aluminum itself. Will try to calculate based on X height vs, X weight at the top frame. Added stiffness is still more important for this first printer. Build volume is shorter, movement at the top is already reduced. Stiffening it will reduce it further over the length of upright we will be using.

## 2025-12-09 Top Frame Stiffeners Created in Cad, Validated by Printing

- 10mm x 20mm x 60mm corner brackets designed yesterday, 2 bolts per rail into t nuts
- Tried to keep the asthetics of the printer correct
- Will use these brackets around the top frame, and also once confirmed non-interference, at each corner of the X/Y around the top
- We have decided to build with a volume of 300x 300y 200z ... shortening this printer will further stiffen the frame. 48V rail moving two print heads as quickly as we can without smashing into each other (hopefully) will require every bit of stiffnes

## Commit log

2025-11-20 Cleaned Repo
    [10mm_extrusion_drill_guide.stl, 110mm_Y_alignment_spacer_x2.stl, 140mm_extrusion_drill_guide.stl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]
2025-11-27 update bom 2
2025-12-05 getting ready for cad
2025-12-07 added working cad - times 2
    [FrameAdjustments.f3d, FrameAndElectronics.f3d]
2025-12-10 CAD Work Frame Stiffeners, Changelog and DesignNo
    [CornerBrackTop.stl, FrameAdjustments.f3d]
2025-12-10 updated bom for parts here parts to come
2025-12-12 Reversal of original CAD separation
    [CornerBrackTop.stl, FrameAdjustments.f3d, FrameAndElectronics.f3d]
2025-12-12 12 stiffener brakects around the top
2025-12-15 Document bracket validation, publish video, post
2025-12-19 CAD, CHANGELOG, DESIGN-NOTES updatew
    [NF3D-Frame-Electronics-Gantry.f3d]
2025-12-20 CAD, CHANGELOG, DESIGN-NOTES updated
    [NF3D-Frame-Electronics-Gantry.f3d]
2025-12-22 updated bom ... will complete all parts here
2025-12-27 cad work - changlog updated
2025-12-29 worked in cad - changelog designnotes
2026-01-04 design notes
    [CornerBracket-Orca.3mf]
2026-01-05 stl directory added - readmes updated - stl files
    [Blind-Corner-Jig.stl, BlindCorner-Drill-Jig-Single.stl, CornerBrackTop.stl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]
2026-01-19 Update to changelog
    [Corner-Piece-Blank-Confirmed.stl, Corner-Size-Test.stl, CornerBracket-FrontLeft-VoronLogo.stl]
